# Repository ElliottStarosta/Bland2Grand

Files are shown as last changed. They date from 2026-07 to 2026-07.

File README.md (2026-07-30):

<div align="center">
  
# Bland2Grand

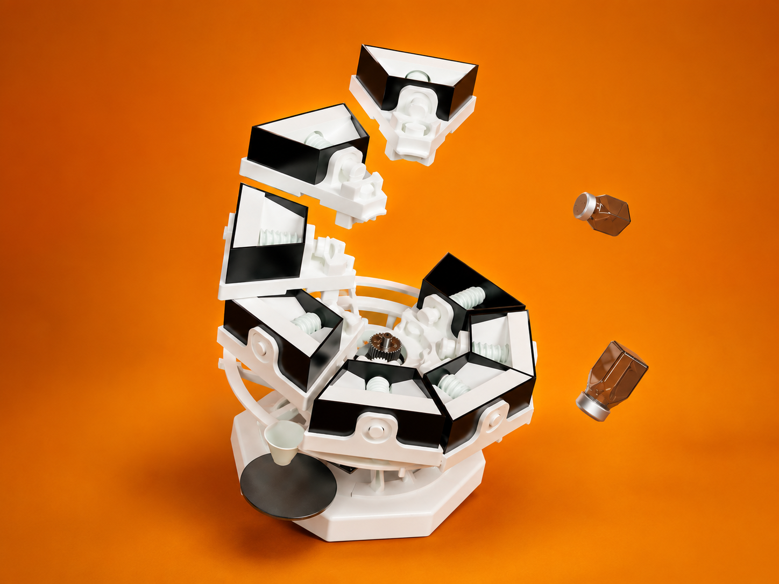
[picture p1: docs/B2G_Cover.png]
Bland2Grand automatic spice dispenser


### Automatic AI‑Powered Spice Dispensing System

**Arduino UNO Q • Flask • React • Load Cell Feedback • Custom Recipe Generation**

Search for a recipe (or build your own blend), choose the number of servings, and Bland2Grand automatically dispenses each spice with real-time weight feedback.

</div>

---

## Features

- 8-slot automatic spice carousel
- Weight-based dispensing with HX711 load cell
- React touchscreen interface
- Flask orchestration backend
- Arduino firmware controlling motors and sensors
- AI-assisted custom spice blend generation
- Live dispense updates using Server-Sent Events

---

## System Architecture

```text
Phone / Browser
      │
      ▼
React UI (5173)
      │
 REST + SSE
      │
      ▼
Flask Backend (5000)
      │
 HTTP + UDP
      │
      ▼
Arduino UNO Q
      │
 GPIO
      │
      ▼
Carousel • Auger • Load Cell
```

The frontend never communicates directly with the Arduino. Flask coordinates every dispense operation, receives progress updates from the Arduino, and streams them to connected clients using Server-Sent Events.

---

## Engineering Journals

Development was documented weekly throughout the project.

| Week | Journal |
|---|---|
|1|https://lying-denim-736.notion.site/Journal-1-33765230a78b8010af24f441907a132c?pvs=73|
|2|https://lying-denim-736.notion.site/Journal-2-33765230a78b808d91aac0a6b3ddb459?pvs=73|
|3|https://lying-denim-736.notion.site/Journal-3-33765230a78b80e9b983e4aa1db35312?pvs=4|
|4|https://lying-denim-736.notion.site/Journal-4-33765230a78b8081bd38f594ebceb503?pvs=73|
|5|https://lying-denim-736.notion.site/Journal-5-33765230a78b80ebb033f5e4358f1c1f|
|6|https://lying-denim-736.notion.site/Journal-6-33765230a78b804fb087c1ad0b55b3ff?source=copy_link|
|7|https://lying-denim-736.notion.site/Journal-7-33765230a78b80bd848ce638972f48d1?pvs=74|
|8|https://lying-denim-736.notion.site/Journal-8-33765230a78b806ebfbeec2ee93a6579?pvs=74|
|9|https://lying-denim-736.notion.site/Journal-9-33765230a78b80528cf1d645e4d33567?pvs=74|
|10|https://lying-denim-736.notion.site/Journal-10-34865230a78b807989e8eb5f8e950e21?pvs=74|
|11|https://lying-denim-736.notion.site/Journal-11-3aa65230a78b80d28e6ce9d19c58a4de|

---

## Design Documentation

| Document | Description | File |
|---|---|---|
| **HRS**  | Hardware Requirements Specification | [docs/HRS.pdf](docs/HRS.pdf) |
| **PDD**  | Preliminary Design Document | [docs/PDD.pdf](docs/PDD.pdf) |
| **HDD**  | Hardware Design Document | [docs/HDD.pdf](docs/HDD.pdf) |
| **MGD**  | Maker's Guide Document | [docs/MGD.pdf](docs/Incomplete_MG.pdf) |

---

## Quick Start

1. Enable the **bland2grand** Windows hotspot.
2. Power the Arduino UNO Q.
3. Run the **Bland2Grand: Full Stack** VS Code task.
4. Forward port **5173** and set visibility to **Public**.
5. Open the forwarded URL on your phone or `http://localhost:5173` on your PC.

---

## Repository Structure

```text
Bland2Grand/
├── Bland2Grand_Arduino/
├── bland2grand-backend/
├── bland2grand-frontend/
├── docs/
├── generate_slots.py
└── .vscode/
```

---

## Updating Spice Slots

Edit `spice_slots.json`, keep slot numbers sequential, then regenerate shared configuration:

```bash
python generate_slots.py
```

---

## First-Time Development Setup

### Backend

```bash
cd bland2grand-backend
python -m venv venv
venv\Scripts\activate
pip install -r requirements.txt
python seed_recipes.py
```

Create `.env`:

```env
ARDUINO_URL=http://192.168.x.x
OPENROUTER_API_KEY=...
AI_MODEL=anthropic/claude-3-haiku
DATABASE_PATH=bland2grand.db
FLASK_PORT=5000
MOCK_ARDUINO=true
```

### Frontend

```bash
cd bland2grand-frontend
npm install
```

### Arduino

Open `Bland2Grand_Arduino` using PlatformIO and upload the firmware.

---

## Hardware

| Component | Purpose |
|---|---|
|Arduino UNO Q|Main controller|
|NEMA 23 + TB6600|Carousel motor|
|NEMA 17 + TB6600|Auger motor|
|HX711 + Load Cell|Weight feedback|

### Pinout

| Signal | Pin |
|---|-----|
|Carousel STEP|D5|
|Carousel DIR|D7|
|Auger STEP|D3|
|Auger DIR|D4|
|HX711 SCK|A0|
|HX711 DOUT|A1|

---

## Troubleshooting

| Problem | Solution |
|---|---|
|Arduino won't connect|Verify hotspot credentials in `main.cpp`.|
|UI loads but dispense fails|Check Flask and Arduino IP configuration.|
|Phone can't access app|Make sure port 5173 is Public.|
|Serial monitor unavailable|Close Arduino IDE or other serial applications.|

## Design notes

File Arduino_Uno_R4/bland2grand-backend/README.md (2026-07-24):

# Bland2Grand backend

Flask server between the React UI and the Arduino. Recipe search, dispense sequencing, SSE progress stream, optional AI blends via OpenRouter.

## Data flow

```
Frontend  ←SSE→  Flask  ←HTTP/UDP→  Arduino
                    ↕
                 SQLite
                    ↕
              OpenRouter (optional)
```

**Mock mode** (`MOCK_ARDUINO=true`, default): simulates dispensing in Python -- no hardware needed for UI work.

**Real mode** (`MOCK_ARDUINO=false`): POSTs each spice to the Arduino and waits for push callbacks before continuing.

## Files

| File | What it does |
|---|---|
| `app.py` | Route definitions (REST + SSE + Arduino push endpoints) |
| `config.py` | Reads `.env` |
| `database.py` | SQLite schema and recipe CRUD |
| `dispense.py` | Session thread, SSE broadcast, mock simulator, UDP weight listener |
| `search.py` | Category shortcut → name search → AI fallback |
| `ai_client.py` | OpenRouter JSON blend generation |
| `seed_recipes.py` | One-time ~100 recipe seed |
| `provision.py` | Push WiFi creds to Arduino over serial |
| `slot_config.py` | Shared slot names (generated from repo root) |

## Setup

```bash
cd bland2grand-backend
python -m venv venv
venv\Scripts\activate          # Windows
# source venv/bin/activate     # macOS/Linux
pip install -r requirements.txt
python seed_recipes.py         # safe to re-run (INSERT OR IGNORE)
python app.py
```

`.env` example:

```env
ARDUINO_URL=http://192.168.x.x
OPENROUTER_API_KEY=sk-or-...
AI_MODEL=anthropic/claude-3-haiku
DATABASE_PATH=bland2grand.db
FLASK_PORT=5000
MOCK_ARDUINO=true
```

## API (frontend-facing)

| Method | Path | Notes |
|---|---|---|
| GET | `/api/health` | `{ status, mock_arduino }` |
| GET | `/api/search?q=` | Up to 6 recipes; may hit AI if DB empty |
| GET | `/api/recipes/<id>` | Single recipe |
| POST | `/api/dispense` | `{ recipe_id, serving_count }` -- starts background thread |
| GET | `/api/status/stream` | SSE -- see event types below |
| POST | `/api/stop` | Cancel + UDP STOP to Arduino |
| POST | `/api/calibrate` | Update slot cal factor |
| POST | `/api/recipe` | Save custom blend |

## Arduino push routes

Called by firmware, not the browser:

| Method | Path | When |
|---|---|---|
| POST | `/api/arduino/indexing` | Carousel moving |
| POST | `/api/arduino/dispense-start` | Auger started |
| POST | `/api/arduino/weight-push` | Live weight (HTTP or UDP relay) |
| POST | `/api/arduino/spice-complete` | One spice done -- unblocks dispense loop |
| POST | `/api/arduino/session-complete` | All spices done |
| POST | `/api/arduino/fault` | Error |

Weight updates also arrive on **UDP port 5001** so the auger loop isn't blocked by HTTP.

## SSE events

`/api/status/stream` emits JSON lines:

| `type` | Useful fields |
|---|---|
| `connected` | Handshake |
| `heartbeat` | Keep-alive |
| `session_start` | `recipe_name`, `slots[]` |
| `indexing` | `slot`, `spice_name`, `slot_index` |
| `dispensing_start` | `target_weight` |
| `weight_update` | `current_weight`, `target_weight` |
| `spice_complete` | `actual`, `target`, `status` |
| `session_complete` | `recipe_name` |
| `session_error` | `message` |

## Search logic

1. Query matches a cuisine keyword (`mexican`, `cajun`, …) → return that category.
2. Else SQL `LIKE` on recipe name.
3. Else call OpenRouter, save as `"AI Generated"`, return the new row.

No API key → step 3 is skipped.

## Database

**recipes** -- `name`, `category`, `description`, plus `s1_cumin` … `s8_cayenne` (grams per serving).

**calibration** -- per-slot `cal_factor` (HX711 counts per gram).

## WiFi provisioning

After flashing firmware:

```bash
python provision.py
# or
python provision.py --port COM3 --ssid MyNet --password secret
```

Sends JSON over serial; Arduino replies `PROV:OK`.

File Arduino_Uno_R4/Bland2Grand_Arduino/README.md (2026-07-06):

# Bland2Grand Arduino firmware

PlatformIO project for the **Arduino UNO Q**. Drives carousel indexing, auger dispensing, load-cell feedback, and talks to Flask over WiFi.

## What runs where

`main.cpp` is the production sketch. It spins a small state machine:

```
IDLE → INDEXING → DISPENSING → PARKING → (next spice or done)
```

- **INDEXING** -- carousel steps to the target slot (shortest CCW path).
- **DISPENSING** -- auger runs; weight pushed over UDP so HTTP doesn't stall steps.
- **PARKING** -- half-rev forward to disengage the spur gear and avoid drips.

`USE_LOAD_CELL` in `main.cpp` picks closed-loop (HX711) vs dead-reckoning (cycle counts only).

## Hardware

| Part | Job |
|---|-----|
| UNO Q | Controller + LED matrix status |
| NEMA 23 + TB6600 | 8-slot carousel |
| NEMA 17 + TB6600 | Auger / half-spur gear |
| HX711 + load cell | Gram feedback (optional) |
### Pins (see `Constants.h`)

| Signal | Pin |
|---|-----|
| Carousel STEP / DIR | D5 / D7 |
| Auger STEP / DIR | D3 / D4 |
| HX711 DOUT / SCK | A1 / A0 |

## Source files

| File | Role |
|---|---|
| `main.cpp` | WiFi, HTTP :80, dispense FSM |
| `Constants.h` | Pins, speeds, gram/rev estimates |
| `CarouselDriver.h` | Slot indexing |
| `AugerDriver.h` | Bulk → settle → nudge dispense |
| `Scale.h` | HX711 wrapper |
| `WiFiComms.h` | WiFi, HTTP server, Flask pushes, UDP weight |
| `SlotConfig.h` | Generated spice names |

## Closed-loop dispense (load cell)

AugerDriver runs three phases when `USE_LOAD_CELL=1`:

1. **Bulk** -- fast run to ~85% of target by cycle count (scale is noisy while spinning).
2. **Settle** -- stop, wait for stable reads.
3. **Nudge** -- one auger cycle at a time until target or max taps.

Per-slot coast EMA learns how much spice keeps falling after the motor stops.

After each spice the auger reverses (back-purge) to re-seat the half-spur gear.

## WiFi

Static IP default: `192.168.137.50` on the `bland2grand` hotspot (gateway `192.168.137.1`).

Credentials at top of `main.cpp`. First boot with empty EEPROM can accept serial provisioning -- see backend `provision.py`.

Flask push target is `FLASK_SERVER_HOST` in `Constants.h`.

UDP: weight → port 5001 on the PC, STOP command listened on 8889.

## Build & flash

```bash
pio run
pio run --target upload
pio device monitor --baud 9600
```

VS Code task **Arduino: Flash** works too.

## PlatformIO libs

```
AccelStepper, HX711, AS5600, ArduinoJson, ArduinoOTA
```

(listed in `platformio.ini`)

## EEPROM map (approximate)

| Address | Content |
|---|---|
| 128–143 | Carousel position backup |
| 200–297 | WiFi SSID/password |

Exact layout may vary -- check `FlowModel.h` / `WiFiComms.h` if you're poking EEPROM directly.

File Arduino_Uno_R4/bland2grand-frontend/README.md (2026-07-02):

# Bland2Grand frontend

Touch-first kiosk UI for the spice dispenser. Dark theme, GSAP transitions, live bowl fill during dispense.

Stack: React 18, TypeScript, Vite, Tailwind, GSAP.

The app only talks to Flask (`/api/*`). Vite proxies those calls to `localhost:5000` in dev.

## Screen flow

```
IdleScreen (tap anywhere to wake)
    ↓
SearchScreen ──→ ResultsScreen ──→ ServingScreen ──→ DispensingScreen ──→ CompleteScreen
    │                                      ↑
    └── CustomRecipeScreen ────────────────┘
```

`App.tsx` owns routing, the 60s idle timer, and dispense lifecycle (`useDispenseStream`).

## Project layout

```
src/
├── App.tsx                 Screen router + idle overlay
├── main.tsx                React mount
├── index.css               Design tokens + global styles
├── types/index.ts          Recipe types, SSE event union
├── slotConfig.ts           Generated spice labels/colors (don't hand-edit)
├── hooks/
│   ├── useDispenseStream.ts   SSE session state
│   ├── useDebounce.ts
│   └── slotAudio.ts           Voice lines per slot
├── components/
│   ├── Header.tsx
│   ├── Bowl.tsx            SVG bowl + spice layers
│   ├── SlotRow.tsx         Per-spice progress bar
│   └── SpiceCard.tsx
└── screens/
    ├── IdleScreen.tsx      Screensaver + useIdleTimer export
    ├── SearchScreen.tsx
    ├── ResultsScreen.tsx
    ├── ServingScreen.tsx
    ├── DispensingScreen.tsx
    ├── CompleteScreen.tsx
    ├── CustomRecipeScreen.tsx
    └── lib/api.ts          Typed fetch helpers
```

## Run locally

Needs Flask on port 5000.

```bash
cd bland2grand-frontend
npm install
npm run dev        # http://localhost:5173
npm run build      # output in dist/
```

## Notable bits

**Bowl.tsx** -- Each spice gets a band in the SVG bowl. Grain texture is procedural (seeded random). Drip animation runs while a slot is actively dispensing.

**useDispenseStream.ts** -- `connectAndDispense()` opens SSE, waits for `connected`, then POSTs dispense so early events aren't dropped. Session state is a reducer over SSE payloads.

**IdleScreen.tsx** -- Full-screen overlay at z-40. `useIdleTimer(timeout, onIdle)` resets via `wakeUp()` when the user taps. GSAP timelines use an `initiated` ref so remounting doesn't replay entrance animations.

**CustomRecipeScreen.tsx** -- Build a blend in g, tsp, or tbsp. Unit picker bubbles animate out with GSAP; values convert through gram equivalents.

## Design tokens

Defined in `index.css` and mirrored in `tailwind.config.js`:

| Token | Value | Use |
|---|---|-----|
| `--color-bg` | `#080706` | Page background |
| `--color-card` | `#161411` | Cards |
| `--color-accent` | `#C8692A` | Primary orange |
| `--color-txt` | `#EDE9E0` | Body text |
| `--color-muted` | `#6A6662` | Secondary text |

Fonts: **Cormorant** (headings), **Outfit** (UI).

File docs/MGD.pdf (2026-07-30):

T E C H N I C A L M A N U A L

B L A N D 2 G R A N D

★

# Maker’s Guide

The Smart, Autonomous Carousel Spice Dispenser

VERSION 1.0 | | | REV. July 30, 2026 | | | DOC. B2G-MG-00 1

### Contents

1

BLAND2GRAND | Maker’s Guide | v1.0

# 1 Introduction

This Maker’s Guide is written for someone who has the printed/purchased parts to build one in front of them and wants to assemble it and get it running. It covers two supported controller boards:
Arduino UNO Q
The primary, currently supported build. The Flask backend, dispense logic, and MCU sketch all run on a single board, launched through Arduino App Lab.
Arduino UNO R4 WiFi
The original build. The backend and frontend run on a separate laptop, communicating with the Arduino over a mobile hotspot.
Follow Section 2 to physically assemble the machine, then Section 3 to install and launch the software for whichever board you have.

i At a Glance
Build Time
One week for printing and
assembly, and one
afternoon for software

Skill Level
Intermediate: soldering, 3D printing, basic CLI

Boards Supported
UNO Q (recommended),
UNO R4 WiFi

# 2 Assembly

### 2.1 Printing the Parts

i Printer and Material Notes
All printing for this build was done on a Bambu P1S and an A1 mini in Bambu Studio. Every part is printed in PETG. Unless a setting is called out below, use the slicer’s default profile. If your slicer doesn’t expose a listed setting, its own default is a safe substitute. A 3D printer with a minimum build volume of 257mm × 257mm × 257mm is required.

Every part in this guide starts from Bambu Studio’s stock 0.20mm Standard @BBL X1C profile. Only the settings listed under each category below are changed; everything else is left at default.
Category Legend
Parts are grouped into three categories by print requirements. This legend is used consistently for the rest of this section:
VEJ | Page 2 of 48

Category | Profile Summary
Category 1 Lightweight | 1 wall loop, 10% infill/wall overlap, support on (tree)
Category 2 Strong | 3 wall loops, 30% infill/wall overlap, support on (tree)
Category 3 Misc | Its own profile: Arachne walls, 3 wall loops, support on (normal)

Full Parts List
Part | Qty
Bevel Gear | 8
Auger Power Shaft | 8
Auger Power Gear (Full Spur) | 8
Auger Motor Mount (Shaft Adapter) | 1
Auger Motor Mount | 1
Auger | 8
Auger Bevel Attachment | 8
Auger End Cap | 8
Base BL, BR, FL, FR | 1 each
Base Plate BL, BR, FL, FR | 1 each
Carousel Drive | 1
Carousel Motor Mount | 1
Carousel Motor Mount (Spacer) | 1
Carousel Track (Upper Trunk) | 1
Carousel Track (Support Arm) | 7
Funnel Support Extension | 1
Internal Gear | 1
Motor Shaft Auger Power Gear (Auger Half Spur) | 1
Plate Holder | 1
Segment | 8
Segment (Lid) | 8
Segment (Insert) | 8
Segment (Fork) | 8
Segment (Container) | 8
Support Plate | 1
Support Ring (Back Ring Track) | 2

Part | Qty
Support Ring (LS Ring Track) | 1
Support Ring (RS Ring Track) | 1
Cycloidal Gearbox (Cover) | 1
Cycloidal Gearbox (Disc) | 1
Cycloidal Gearbox (Hover) | 1
Cycloidal Gearbox (Input) | 1
Cycloidal Gearbox (Output) | 1

Category 1: Lightweight
Part | Qty
Base BL, BR, FL, FR | 1 each
Base Plate BL, BR, FL, FR | 1 each
Carousel Track (Upper Trunk) | 1
Carousel Track (Support Arm) | 7
Funnel Support Extension | 1
Plate Holder | 1
Segment | 8
Segment (Lid) | 8
Segment (Insert) | 8
Segment (Fork) | 8
Segment (Container) | 8
Setting | Value
Wall Loops | 1
Infill / Wall Overlap | 10%
Support | On (Tree)

Strength tab | Support tab
Figure 1: Slicer settings for Category 1 (Lightweight) parts.

Category 2: Strong
Part | Qty
Carousel Drive | 1
Carousel Motor Mount | 1
Carousel Motor Mount (Spacer) | 1
Internal Gear | 1
Motor Shaft Auger Power Gear (Auger Half Spur) | 1
Support Plate | 1
Cycloidal Gearbox (Cover) | 1
Cycloidal Gearbox (Disc) | 1
Cycloidal Gearbox (Hover) | 1
Cycloidal Gearbox (Input) | 1
Cycloidal Gearbox (Output) | 1
Setting | Value
Wall Loops | 3
Infill / Wall Overlap | 30%
Support | On (Tree)

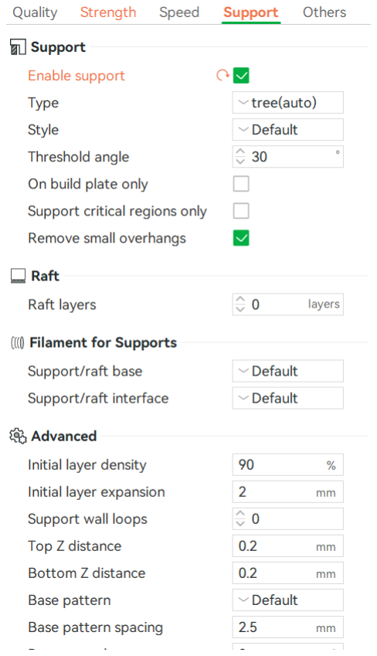
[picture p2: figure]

Strength tab | Support tab
Figure 2: Slicer settings for Category 2 (Strong) parts.

Category 3: Misc
Part | Qty
Auger | 8
Setting | Value
Wall Generator | Arachne
Layer Height | 0.2mm (initial 0.16mm)
Wall Loops | 3
Support | On (Normal)
Quality tab (1) | Quality tab (2)

Strength tab

Support tab

Figure 3: Slicer settings for Category 3 (Misc) parts, the Auger.

### 2.2 Mechanical Assembly

This section walks through the full mechanical build of Bland2Grand in eight parts: the auger motor, the carousel motor and cycloidal gearbox, the base, the load cell, the carousel segments, the tree trunk, and final assembly. Build the sub-assemblies in order, as each part is set aside and used in a later step.

i Before You Start
Have all printed parts from Section 2.1 sorted and within reach, along with super glue (or threadlocker), a hex key set, and the hardware called out in each step.

Part 1: Auger Motor Assembly

### 1 With the Auger Motor Mount (Shaft Adapter) and the half spur gear, super glue

the gear onto the shaft as shown below.

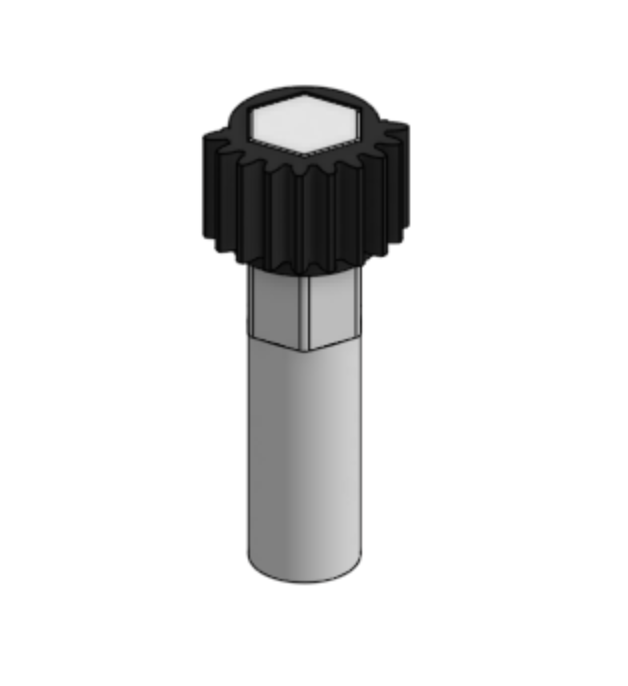
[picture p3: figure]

Figure 4: Half spur gear glued onto the auger motor shaft adapter.

### 2 Place the auger motor into the mount through the slit. Insert the four #6-32 ³

8

”
bolts into the motor (the motor is tapped, so no nuts are needed on this side).

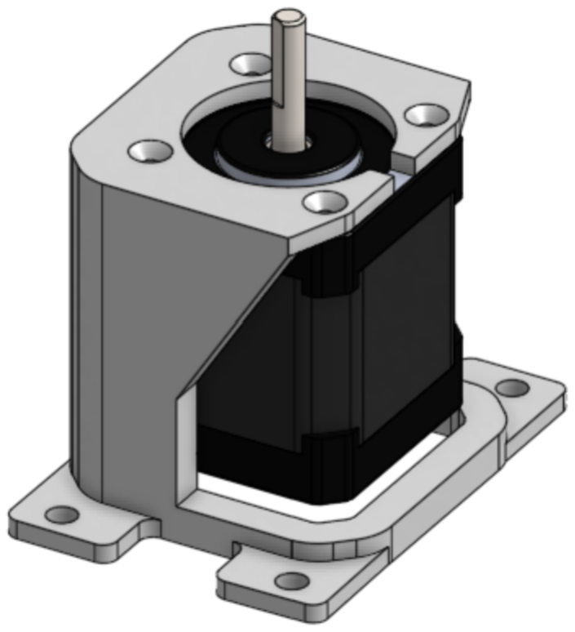
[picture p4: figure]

Figure 5: Auger motor seated into the Auger Motor Mount, viewed from the shaft side.

### 3 A second view of the same joint, showing the four #6-32 3

8

” bolts driven into the
motor’s tapped mounting holes.

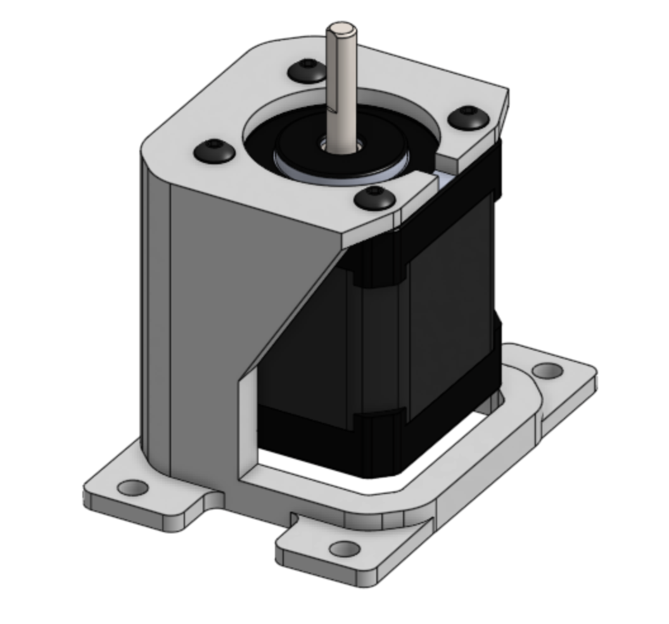
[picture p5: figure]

Figure 6: Auger motor mount, alternate angle showing #6-32 3
8

” bolt placement.

4 Slide the glued gear and shaft adapter (from Step 1) onto the motor shaft.

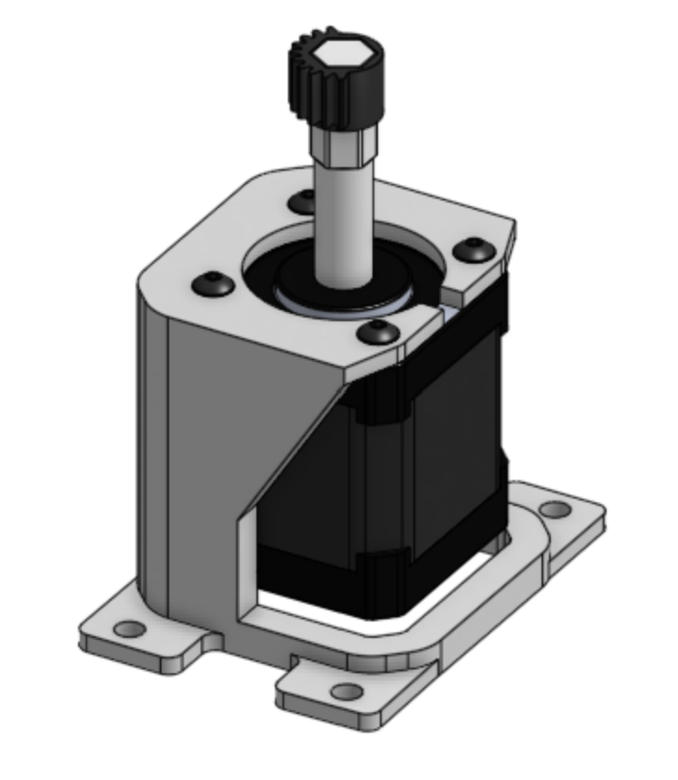
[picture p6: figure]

Figure 7: Gear and shaft adapter slid onto the auger motor shaft. Set the completed Auger Motor assembly aside.

Part 2: Carousel Motor and Gearbox Assembly

### 5 Place the carousel motor into the Carousel Motor Mount, ensuring the holes

on the mount line up with the holes on the motor.

Figure 8: Carousel motor aligned with the Carousel Motor Mount.

### 6 Place the gearbox spacer and housing onto the motor, ensuring that all mounting

holes are properly aligned.

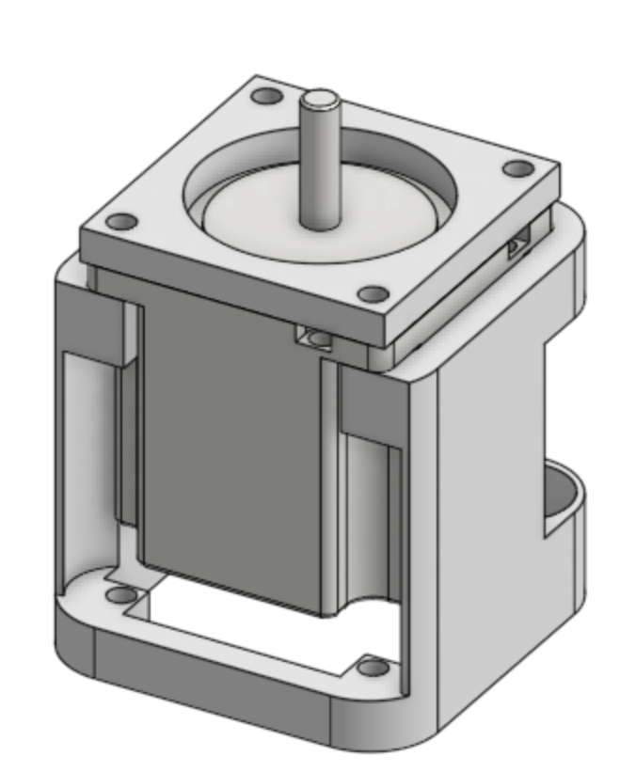
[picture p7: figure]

Figure 9: Gearbox spacer and housing installed onto the motor.

### 7 With the motor secured, the cycloidal gearbox housing sits on top, ready for the

disc and input adapter.

Figure 10: Cycloidal gearbox housing positioned above the mounted carousel motor.

### 8 Place the Cycloidal Gearbox (Disc) into the housing, then insert the input

adapter onto the motor shaft and into the disc.

Figure 11: Cycloidal disc lowered into the housing with the input adapter engaging the motor shaft.

9 A closer view showing the input adapter fully seated through the disc’s central bore.

Figure 12: Input adapter seated through the cycloidal disc.

10 Insert the output carriage into the holes in the cycloidal disc, as shown below.

Figure 13: Output carriage pins inserted into the cycloidal disc’s offset holes.

### 11 The Cycloidal Gearbox (Output) plate, which the carriage pins pass through to

transmit rotation.

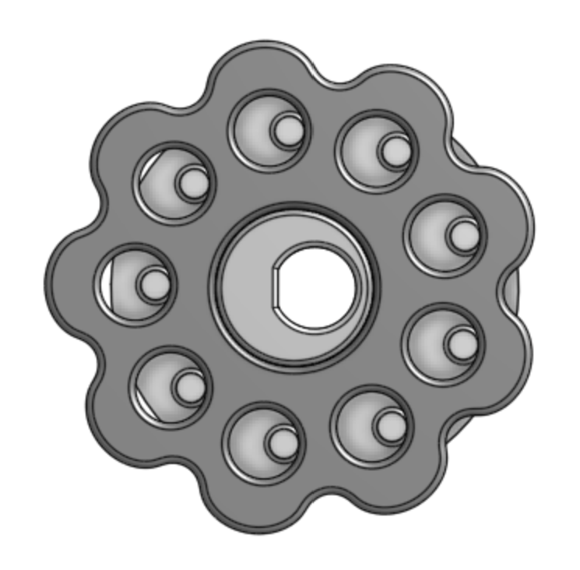
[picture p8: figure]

Figure 14: Cycloidal Gearbox (Output) plate.

12 Place the carousel drive gear in the cover between the top and bottom plates, as shown below. Then lower both parts onto the gearbox assembly.

Figure 15: Carousel drive gear seated in its cover between the top and bottom plates.

### 13 An exploded view of the same joint, showing the drive gear, cover, and gearbox

stack in assembly order.

Figure 16: Exploded view of the carousel drive gear over the assembled gearbox.

14 The stack fully lowered and seated together.

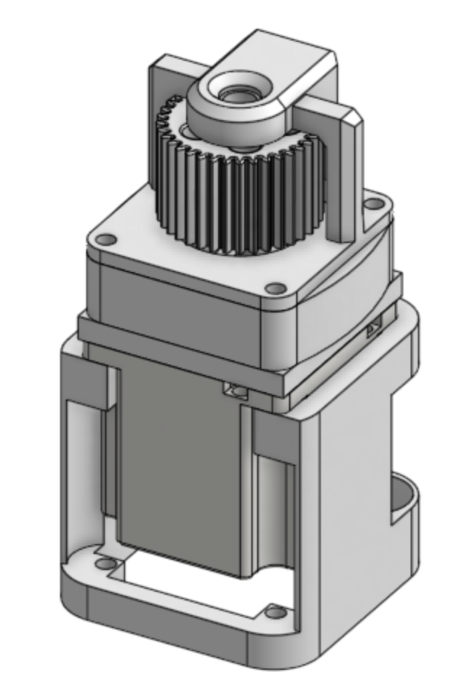
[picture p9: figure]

Figure 17: Carousel drive gear cover seated onto the completed gearbox assembly.

### 15 Insert four #10-32 1 ½” bolts into the holes and add matching nuts on the other

side. Tighten by hand.

Figure 18: Four #10-32 bolts and nuts securing the gearbox cover stack.

Set the completed Carousel Motor and Gearbox assembly aside.
Part 3: Base Assembly

### 16 Lay out the four Base (BL, BR, FL, FR) components and the dovetail key that joins

them.

Figure 19: The four base quadrants and dovetail key, prior to assembly.

### 17 Apply glue to the dovetail, then insert it into the center junction of the four

base components, ensuring it is properly aligned as shown below.

Figure 20: Dovetail key glued and inserted at the center junction of the four base quadrants.

### 18 Place the auger motor assembly (from Part 1) onto the base, aligning the

mounting holes with the designated holes as shown below. Insert four #10-32 1” bolts from underneath the base and secure them with four matching nuts. Tighten the bolts to firmly fasten the auger motor assembly in place.

Figure 21: Auger motor assembly secured to the base plate using four #10-32
1” bolts and matching nuts.

### 19 A closer view confirming the motor mount’s holes line up with the base before fas-

tening.

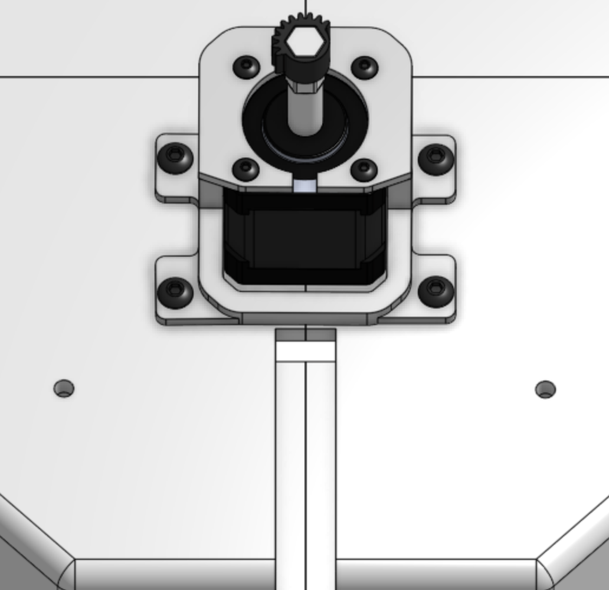
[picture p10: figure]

Figure 22: Close-up of the auger motor mount seated on the base.

20 Place the carousel motor and gearbox assembly (from Part 2) onto the base, as shown below. Insert four #10-32 1” bolts, this time with the bolt heads on the underside of the base and matching nuts on the topside.

Figure 23: Carousel motor and gearbox assembly aligned above the base’s center bore.

### 21 A view from underneath the base, showing the bolt heads seated against the base

with the center dovetail key visible through the bore.

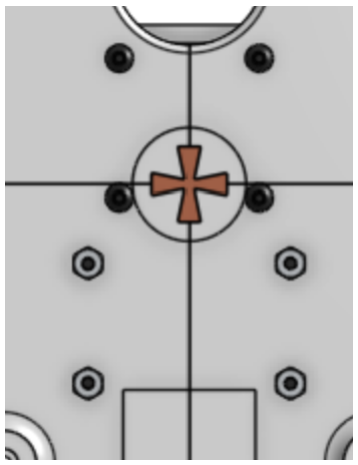
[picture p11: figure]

Figure 24: Underside view of the base showing bolt heads and the center dovetail key.

Set the Base assembly aside.

Part 5: Load Cell
22 With the load cell, super glue one of the load cell mounts to one of its ends, lining it up carefully.

Figure 25: Load cell mount glued to one end of the load cell.

### 23 Super glue the load cell mount and base to the flat part on the inside of the

base, as shown below.

Figure 26: Load cell and mount glued into position on the inside of the base.

24 A closer view of the load cell mount seated flush against the base’s inner wall.

Figure 27: Close-up of the load cell mount glued to the base’s inner face.

### 25 With the other load cell mount, super glue it to the opposite corner of the first

load cell mount, facing upwards.

Figure 28: Second load cell mount glued facing upward at the opposite corner.

26 Then, super glue the Plate Holder onto the load cell mount.

Figure 29: Plate Holder glued onto the upward-facing load cell mount. Part 6: Carousel Segment
Build one segment completely, then repeat the whole part seven more times for a total of eight.

### 27 Place a bearing into the bearing well of one of the carousel segments, making

sure it sits at the bottom of the well.

Figure 30: Bearing seated in a carousel segment’s bearing well.

28 Then place a Segment (Container) into the slot. Set aside.

Figure 31: Segment container placed into the segment shell.

29 With the Segment (Insert), place an auger into the tunnel as shown below. Then carefully lower the insert/auger into the container.

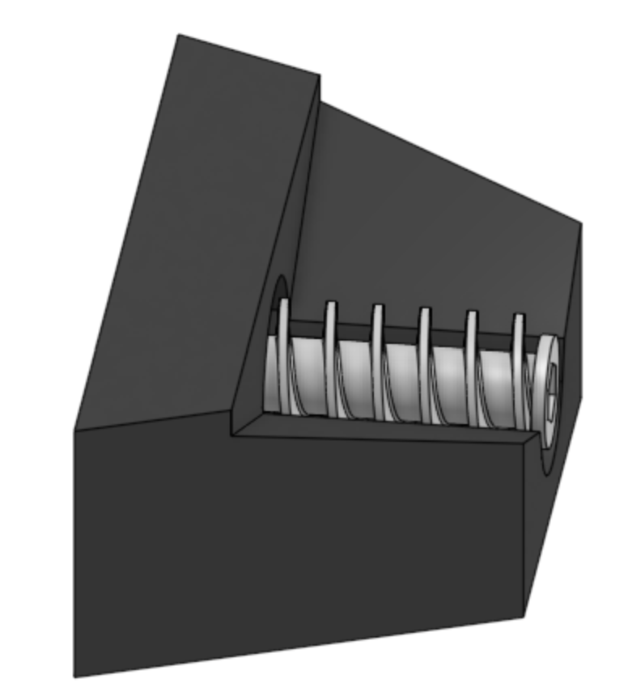
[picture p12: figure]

Figure 32: Auger placed into the tunnel of the segment insert.

30 The insert and auger lowered together into the container.

Figure 33: Segment insert and auger lowered into the segment container.

### 31 With the rear Auger End Cap, apply super glue to the hex side and insert it into

the fitting in the auger. Repeat this process on the front end cap.

Figure 34: Rear auger end cap glued and inserted into the auger’s hex fitting.

### 32 Front end cap and bearing detail, showing the hex bore that mates with the auger

shaft.

Figure 35: Front auger end cap and bearing hex-bore detail.

### 33 Turn the assembly over. With the Segment (Fork), apply super glue to the

spaces shown below and insert the fork.

Figure 36: Segment fork glue points on the underside of the segment.

34 The fork seated and glued into place on the flipped segment.

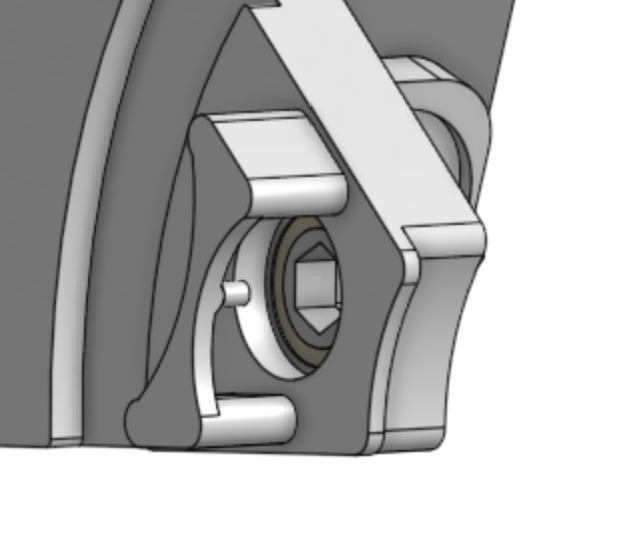
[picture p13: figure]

Figure 37: Segment fork inserted and glued in place.

35 Place one of the Auger Power Gears (Full Spur) onto the stud of the fork.

Figure 38: Full spur gear placed onto the fork’s stud.

### 36 Place a Bevel Gear onto the auger end cap, applying a bit of super glue to the

shaft beforehand.

Figure 39: Bevel gear glued onto the auger end cap’s shaft.

37 Place a matching bevel gear on the bearing, lining it up with the hex bore. Then insert the hex shaft through both gears.

Figure 40: Matching bevel gear aligned to the bearing’s hex bore.

38 The hex shaft fully seated, meshing both bevel gears.

Figure 41: Hex shaft seated through the meshed bevel gear pair.

i Repeat for All Eight
Repeat Steps 27–38 seven more times, for a total of eight completed segments, before continuing.

39 Line up all eight segments side by side, forming the full carousel ring.

Figure 42: All eight segments arranged side by side, viewed from above.

40 The segments joined together into a single ring assembly.

Figure 43: Eight segments joined into the assembled carousel ring.

### 41 With the ring gear, place it in the center of all the segments and super glue it

in place.

Figure 44: Ring gear glued into the center of the assembled carousel. Set the completed carousel assembly aside.

Part 7: Tree Trunk

### 42 Place the lower trunk (identifiable as the one with the opening in the ring) onto

the base plate, encompassing the gearbox assembly.

Figure 45: Lower trunk lowered onto the base plate around the gearbox assembly.

### 43 Insert a #10-32 3

4

” bolt through each mounting hole in the base, then secure it with a matching nut on the topside. Ensure that all bolts are properly seated and tightened.

Figure 46: Support arms secured to the base plate using #10-32 bolts and nuts.

### 44 The lower trunk fully seated on the base, with the carousel drive and motor visible

through the center opening.

Figure 47: Lower trunk seated on the base, carousel drive visible through the center.

### 45 Place the upper trunk onto the lower trunk, lining up the holes between the

two. With the support plate, place it as shown.

Figure 48: Upper trunk aligned onto the lower trunk with the support plate positioned.

46 The upper and lower trunk sections joined, ready for fastening.

Figure 49: Upper and lower trunk sections joined together.

### 47 Insert a #10-32 3

4

” bolt and matching nut through each of the mounting holes as shown. Ensure that the bolts are properly seated and tightened.

Figure 50: #10-32 3
4

” bolts and matching nuts installed through the trunk’s aligned mounting holes.

### 48 Following the image below as a guide, insert the support arms and funnel into

the correct slots, then secure each component using two #10-32 3
4

” bolts and
matching nuts.

Figure 51: Support arms and funnel secured in the trunk’s slots using #10-32 3/4” bolts and matching nuts.

49 Support arms and funnel fastened in place with bolts and nuts.

Figure 52: Support arms and funnel secured with bolts and nuts.

Part 8: Final Assembly

### 50 With the support ring, place it on the support arms so the opening sits above

the funnel. Add super glue at the seams to lock it in place.

Figure 53: Support ring placed on the support arms above the funnel.

### 51 With the assembled carousel (from Part 6), place it on the ring track of the

upper trunk, making sure the ring gear meshes with the carousel drive.

Figure 54: Assembled carousel lowered onto the upper trunk’s ring track.

### 52 Place all the electronics and wiring into the base (Section 2.3), then enclose

it with the base plates.

Figure 55: Electronics and wiring routed into the base before closing with the base plates.

i Mechanical Build Complete
With Part 8 finished, the mechanical assembly is done. Continue to Section 2.3 for the electrical wiring if it isn’t already in place, then to Section 3 to install and launch the software.

### 2.3 Electrical Wiring

All wiring is routed beneath the base plate, keeping the carousel deck and inside the tree trunk clear of cable clutter. The PERF board, stepper drivers, and HX711 are mounted to the underside of the base; only the motor leads pass up through the base into the tower.

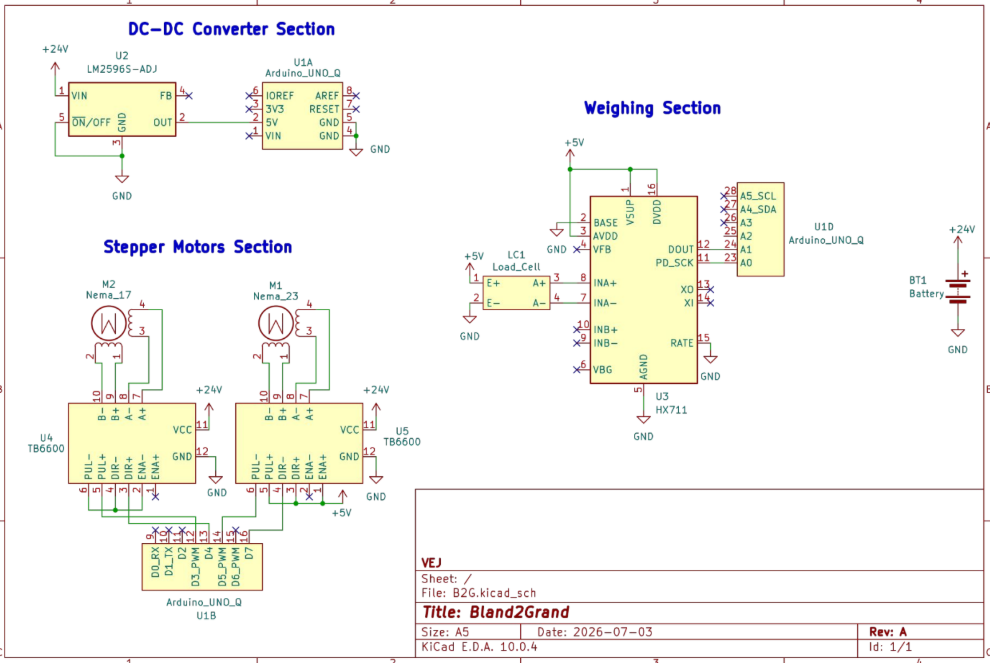
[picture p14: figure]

Figure 56: Full electrical schematic for Bland2Grand.

1 Plug the 4-pin wires into the NEMA 23 and NEMA 17 motors.

Figure 57: 4-pin wire connectors seated into the NEMA 23 and NEMA 17 motors.

2 Thread the wires through the routing hole shown below, down into the base.

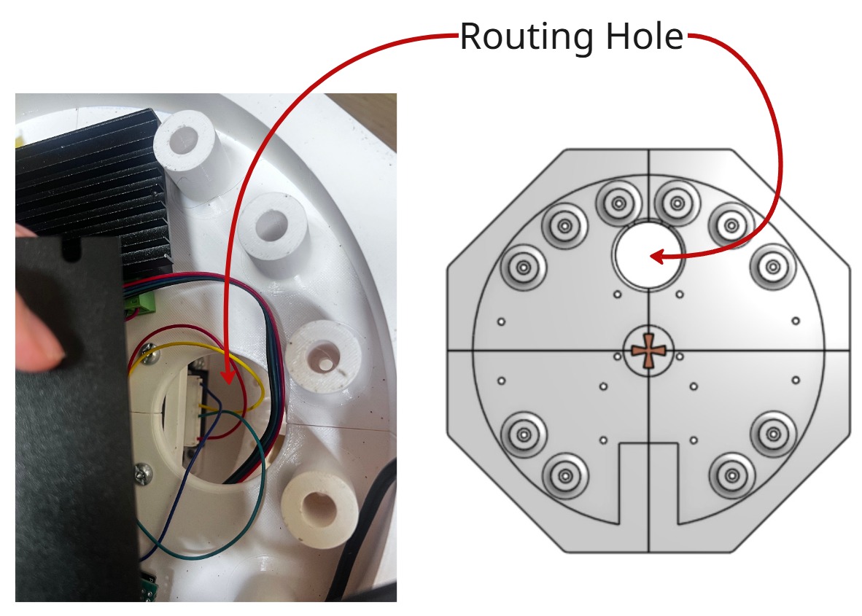
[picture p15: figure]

Figure 58: Motor wires threaded through the routing hole into the base.

### 3 Wire and solder the remaining connections according to the schematic

above.

Figure 59: Finished wiring, soldered and connected per the schematic.
What's Underneath the Base
- Controller board (UNO Q or UNO R4 WiFi): centered on the sub-plate, standoffmounted for airflow and easy access to the USB port.

- Stepper drivers: one per auger motor, mounted in a row along one edge, each wired to its corresponding controller pin group per the schematic.
- HX711 load cell amplifier: mounted close to the load cell itself to keep that signal run short, then a single 4-wire cable carries the amplified signal up to the controller.
- Power distribution terminal: splits the 24 V input to the motor drivers and steps it down as needed for the controller and load cell amplifier.

! Disconnect power before wiring changes
Always unplug the 24 V supply before connecting or disconnecting anything from the base. The stepper drivers in particular can be damaged if motor leads are connected or removed

# 3 Code and Software Setup

All source code for Bland2Grand is hosted on GitHub: github.com/ElliottStarosta/ Bland2Grand. (https://github.com/ElliottStarosta/Bland2Grand) The repository contains separate, self-contained builds for each supported board. Set up the one that matches your hardware.

### 3.1 Arduino UNO Q Setup (Recommended)

The UNO Q build runs the whole system (MCU sketch, Flask backend, REST API, SSE stream, and the built React frontend) as a single App Lab app on the board itself. There is no separate laptop backend/frontend to run.
Phase 1: Download the Project
1 Navigate to the Bland2Grand GitHub repository. (https://github.com/ElliottStarosta/Bland2Grand)

Figure 60: The Bland2Grand GitHub repository page.

2 Locate and click on the latest release.

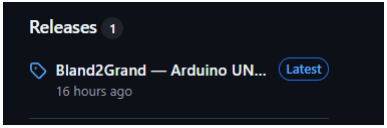
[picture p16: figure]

Figure 61: Latest release on the Releases page.

3 Scroll to the Assets section at the bottom of the release.

Figure 62: Assets section at the bottom of a release.

4 Download the zip file: Bland2Grand_Arduino_Uno_Q.zip.

Figure 63: Downloading Bland2Grand_Arduino_Uno_Q.zip from the Assets list.

Phase 2: Deploy to Arduino / App Lab
5 Open App Lab.

6 Select your board.

Figure 64: Selecting the connected UNO Q board in App Lab.

7 Click Create new app in the top right-hand corner.

Figure 65: The “Create new app” button in App Lab.

8 Click Import App and select the .zip file you downloaded in Phase 1.

Phase 3: Configure API Credentials
The AI-assisted custom blend feature calls out to OpenRouter. An API key is required for this feature to work (the rest of the app — search, dispensing, calibration — works without it).

9 Go to the OpenRouter keys page. (https://openrouter.ai/sign-in?redirect_url=https%3A%2F%2Fopenrouter.ai%2Fworkspaces%2Fdefault%2Fkeys)

10 Click New Key.

Figure 66: The “New Key” button on the OpenRouter keys page.

11 Fill out the required information.

Figure 67: OpenRouter new key creation form.

### 12 Copy the key shown on the confirmation screen right away — OpenRouter will

not show it to you again.

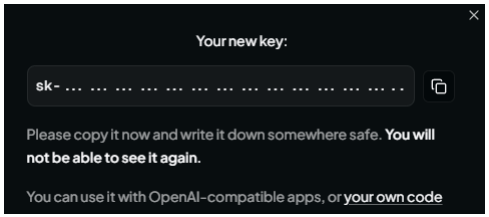
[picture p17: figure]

Figure 68: The one-time key reveal screen after creating a key.

### 13 Update the relevant environment variables for the app, most importantly

OPENROUTER_API_KEY.

Figure 69: Example environment configuration for the UNO Q app.

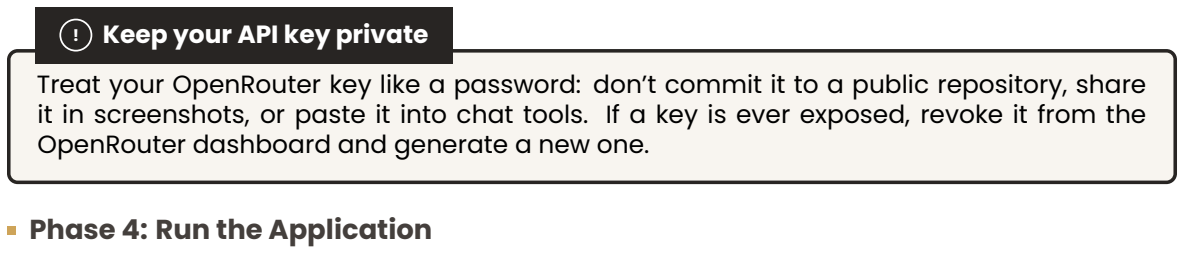
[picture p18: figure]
! Keep your API key private; Phase 4: Run the Application

Treat your OpenRouter key like a password: don’t commit it to a public repository, share it in screenshots, or paste it into chat tools. If a key is ever exposed, revoke it from the OpenRouter dashboard and generate a new one.

### 13 Set the application to run on startup by clicking the down arrow at the top

left-hand side of the screen, next to “Bland2Grand”.

Figure 70: The startup dropdown next to the app name in App Lab.

14 Toggle the Run at startup option to enabled.

Figure 71: Enabling the “Run at startup” toggle.

### 15 Click the Run button in the top right-hand corner of the screen. App Lab uploads

the MCU sketch and starts the Flask app on the board’s Linux side.

### 16 Access the web server by opening the board’s address on port 5000 (the port de-

clared in app.yaml) in your browser.

17 You are now ready to use Bland2Grand.

i Why enable Run at startup
With Run at startup enabled, the UNO Q automatically relaunches the Bland2Grand app any time it’s powered on or rebooted, so you don’t need App Lab open to bring the machine back up after a power cycle.

i No separate frontend server
Unlike the UNO R4 build below, the UNO Q serves the built React frontend directly from the same Flask app that handles the API, so there is nothing else to start or forward — one board, one port, one app.

### 3.2 Arduino UNO R4 WiFi Setup

The UNO R4 build splits the system across three pieces: firmware on the Arduino, a Flask backend, and a React frontend, both of the latter run on a laptop and communicate with the Arduino over WiFi. This section assumes the hardware is already assembled
and wired per Section 2, and that the Bland2Grand_Arduino, bland2grand-backend, and bland2grand-frontend folders (and the provided .vscode/tasks.json) are on the laptop
that will run the software.
Hardware Power-On

### 1 Place the machine on a flat, level surface — the load cell platform must stay level

to within 2◦

for accurate readings.

2 Connect the 24 V power supply to the wall.

3 Confirm each of the 8 spice containers is loaded and seated.

4 Place an empty bowl on the scale platform. The scale tares before each dispense, so the exact bowl weight does not matter.

### 5 Make sure the host laptop is powered on and ready to start its mobile hotspot (see

below). The Arduino and the phone running the web app both need to join it. Launching the Software
All software is launched from VS Code using the provided tasks.json. Open the project workspace in VS Code, then open the Command Palette with Ctrl+Shift+P and select Tasks: Run Task.

Figure 72: VS Code Command Palette showing “Tasks: Run Task” selected.
Two compound tasks are available:

Task Name | What it does
Bland2Grand: Full Stack | Flashes firmware to the Arduino, opens the serial monitor, starts the Flask backend, and starts the Vite frontend, which is all in parallel. Use this for a full bring-up from scratch.
Bland2Grand: Backend + Frontend | Starts only the Flask backend and the Vite frontend. Use this when the Arduino is already flashed and running. This is the task to run for a demo.

i What Full Stack does automatically
The Arduino: Flash + Serial subtask does three things before flashing: it starts the Windows mobile hotspot (so the Arduino has a network to connect to), kills any open serial monitor that would block the port, then runs pio run --target upload followed by pio device monitor --baud 9600. No manual hotspot setup or port management is needed.

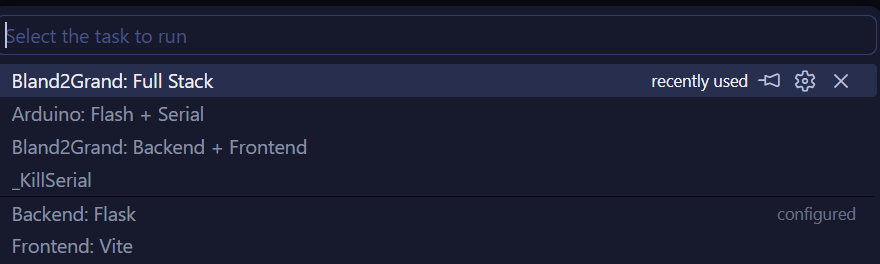
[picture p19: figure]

Figure 73: VS Code task picker showing the available Bland2Grand tasks.
Once the Backend + Frontend task is running, the web app is accessible from any device on the same network at:

http://{laptop_ip}:5173
The laptop’s IP address is printed in the Vite terminal panel when it starts. On the Arduino’s serial monitor you will also see the IP it received from the hotspot, which confirms the two devices are on the same subnet.
First-Time Backend Setup
If this is the first time running the backend on this laptop, set it up once before using the VS Code tasks:

1 cd bland2grand -backend
2 python -m venv venv
3 venv\Scripts\activate
4 pip install -r requirements.txt 5 python seed_recipes.py

Create a .env file in bland2grand-backend/:

1 ARDUINO_URL=http://192.168.x.x
2 OPENROUTER_API_KEY=YOUR_KEY_HERE
3 AI_MODEL=anthropic/claude -3-haiku 4 DATABASE_PATH=bland2grand.db
5 FLASK_PORT=5000
6 MOCK_ARDUINO=true

1 cd bland2grand -frontend
2 npm install
Open Bland2Grand_Arduino in PlatformIO once to confirm it builds before relying on the VS Code task to flash it.

MOCK_ARDUINO=true simulates dispensing in software with no hardware attached. This is useful for testing the app without the machine. Set it to false once the Arduino is flashed and wired, so the backend talks to the real hardware.

# 4 Using Bland2Grand

Once your board is flashed and the app is running (Section 3.1 or Section 3.2), everything from here on is identical regardless of which board you built. You interact with Bland2Grand entirely through a web app on your phone: the machine handles all indexing, dispensing, and weight confirmation autonomously and reports the result back in real time.

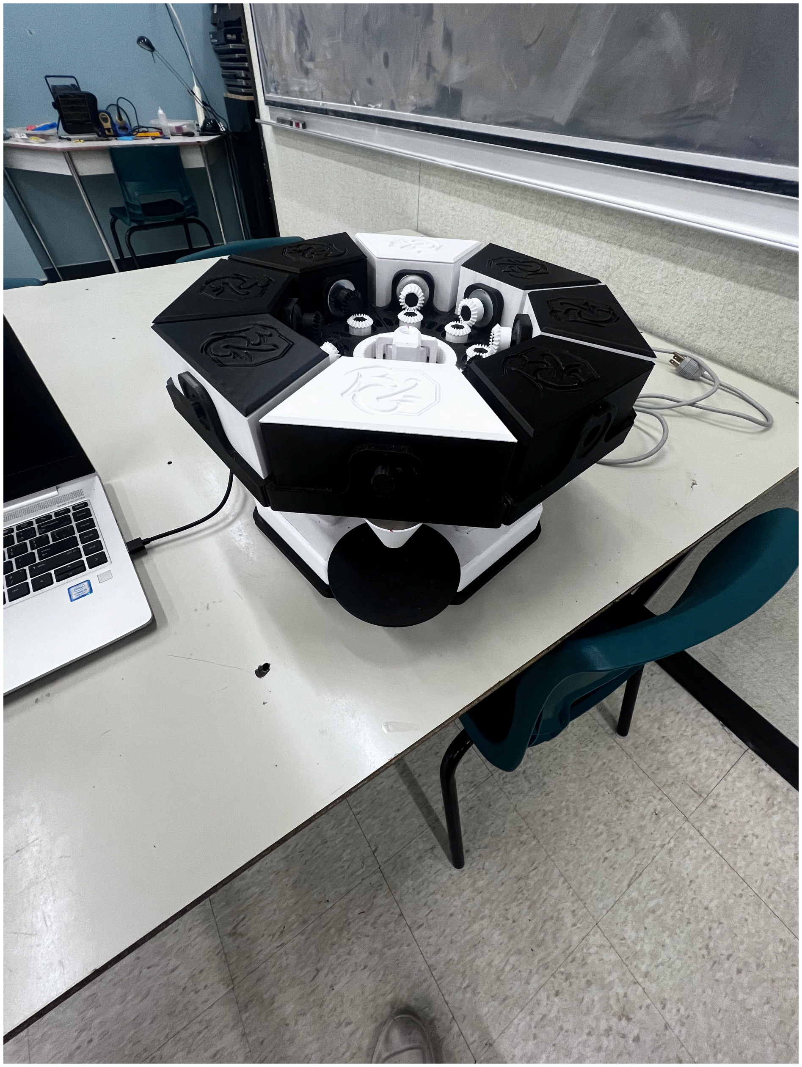
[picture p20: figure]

Figure 74: Bland2Grand assembled system, ready to dispense.

### 4.1 Powering On and Preparing to Dispense

### 1 Place the machine on a flat, level surface. The load cell platform must stay level

to within 2° for accurate readings — avoid uneven countertops or surfaces that vibrate.

### 2 Connect power to the board. 24 V for the UNO R4 build, or the UNO Q’s own power

input if that’s your build.

### 3 Verify spice containers are loaded. Each of the 8 slots should hold its designated

spice (see the slot map in Section 4.3). Friction-fit lids pull straight off — do not twist.

### 4 Place an empty bowl on the scale platform. Sit it flat and centred — the scale

tares before each dispense, so the exact bowl weight doesn’t matter.

Figure 75: Bowl placed on the scale platform at the base of the machine.

### 5 Confirm the app is reachable. Open the board’s URL on your phone (port 5000 for

UNO Q, or http://{laptop_ip}:5173 for UNO R4) and make sure the phone is on the same network as the board.

i Same app, either board
The interface below is served identically whether the Flask app is running on the UNO Q itself or on a laptop for the UNO R4 build. Once the URL loads, the rest of this section applies exactly as written.

### 4.2 Using the Mobile Web App

Idle Screen: Tap to Wake
When you first open the URL, the idle screen appears: ambient coloured orbs drift across a dark background with the Bland2Grand logo and a pulsing tap indicator. Tap anywhere to wake the app.

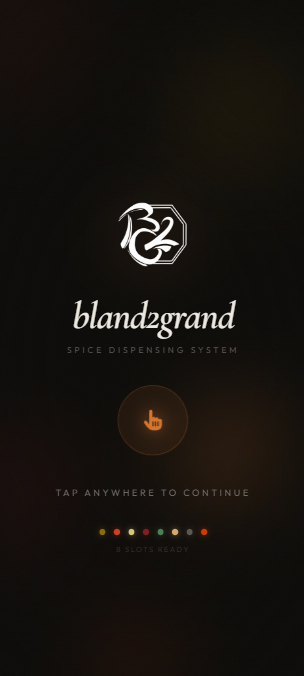
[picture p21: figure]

Figure 76: Idle screen. Tap anywhere to continue.

Search Screen: Find a Recipe
The search screen offers three ways to find a recipe:
1. Type a dish name into the search bar. Results appear automatically after a 2.5-second pause. If no local match exists, the AI generates a blend and saves it to the database for next time.
2. Tap a Featured Blend tile to jump directly to a popular recipe without searching.
3. Tap a cuisine category (Mexican, Indian, Italian, etc.) to browse everything in that category.

Figure 77: Search screen showing the search bar, featured blends, and cuisine category grid.
If the dish isn’t in the local database yet, an AI loading overlay appears while the blend is generated; this takes 1–3 seconds and only happens once per unique dish name. Every future search for the same dish is served instantly from the cache.

AI generating a blend

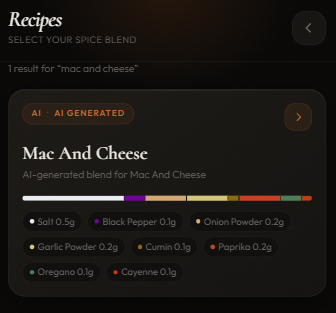
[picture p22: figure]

Generated result

Figure 78: AI loading overlay shown while generating a new recipe, and the resulting spice blend.

Results Screen: Choose Your Blend
Up to six matching recipes appear as cards, each showing the recipe name, a cuisine badge, a proportional spice colour bar, and the gram amount per serving for every active spice. Tap a card to select it.

Figure 79: Results screen showing matching recipe cards with spice colour bars and gram breakdowns.

Serving Screen: Set Portions
Use the large +/- buttons or the quick-pick row (1, 2, 4, 6, 8) to set how many servings to dispense. Gram amounts update live as you adjust. When ready, tap Dispense N servings.

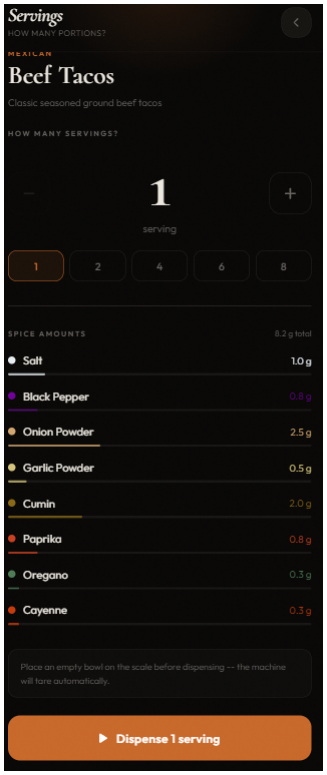
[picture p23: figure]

Figure 80: Serving screen with the counter set and gram breakdown updating live. Dispensing Screen: Watch It Work
While dispensing, the screen shows:

- A bowl visualisation that fills with layered spice in each slot’s colour as weight accumulates.
- A per-spice progress row with a live bar, status icon (rotating for indexing, spinning for dispensing, checkmark for done), and current vs. target weight.
- A circular progress ring showing overall completion percentage.
- A status line showing the current action (e.g. “Rotating…” or “Cumin”).
Each spice plays a voice announcement when the carousel reaches its slot.

Pulling the bowl off the scale during dispensing will throw off the weight readings for the rest of the session. Wait for the Complete screen before touching it.

Figure 81: Dispensing screen mid-session: bowl filling, per-spice rows, and progress ring.

Complete Screen: Your Blend Is Ready
Once every spice has been dispensed, the screen transitions to Ready, showing:
- A green checkmark (or amber warning if any slot timed out).
- A summary card listing the actual dispensed weight for each spice against its target.
- The total dispensed weight.
Retrieve your bowl and start cooking. Tap Start a new blend to return to the search screen.

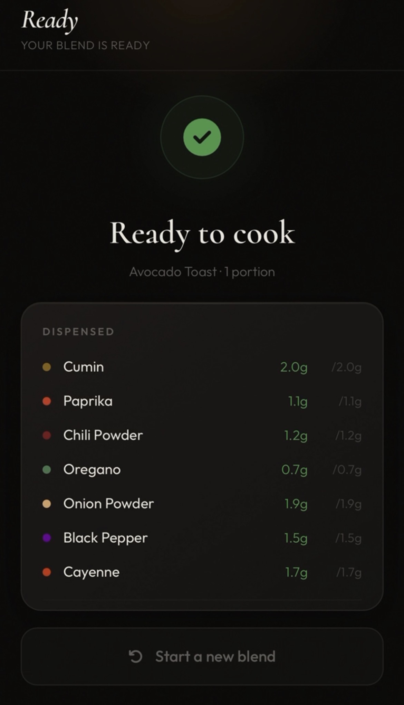
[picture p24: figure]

Figure 82: Complete screen showing the dispensed summary with accuracy indicators. Custom Recipe Builder
Tap Create Custom Blend on the search screen to build your own blend from scratch:
1. Enter a blend name and optional description at the top.
2. For each of the 8 slots, tap the unit label (tsp, tbsp, or g) to cycle between units. The amounts convert automatically using each spice’s density constant.

3. Use the +/- buttons to set the amount for each spice. A live proportional bar chart updates as you adjust.
4. Tap Save & Dispense to write the recipe to the database and proceed to the serving screen.

Figure 83: Custom recipe builder showing per-slot amount controls, unit picker bubbles, and live spice bar.

### 4.3 Refilling Containers

Each container has a friction-fit lid. Ensure the machine is not actively dispensing before opening the lid. Fill the container, then replace the lid, pressing it down until it is firmly seated.

Slot | Spice | Slot | Spice
1 | Salt | 5 | Cumin

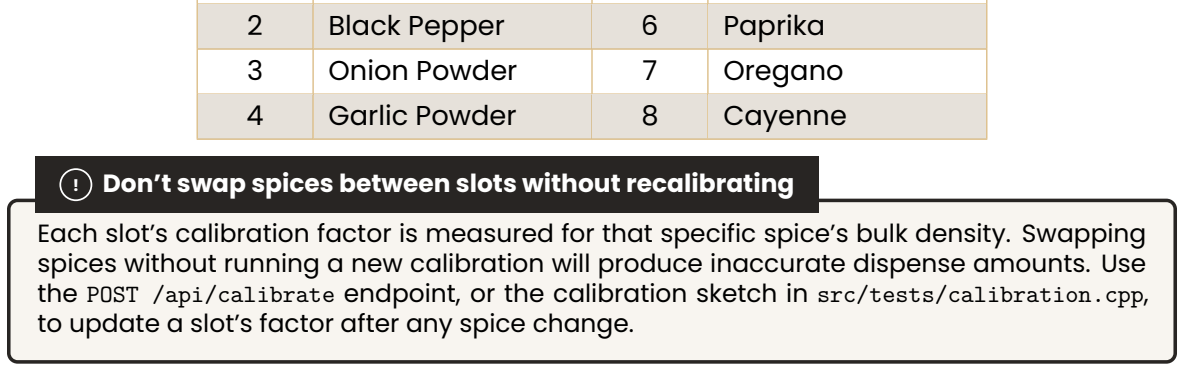
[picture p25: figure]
Black Pepper; Paprika; Onion Powder; Oregano; Garlic Powder; Cayenne

! Don’t swap spices between slots without recalibrating
Each slot’s calibration factor is measured for that specific spice’s bulk density. Swapping spices without running a new calibration will produce inaccurate dispense amounts. Use
the POST /api/calibrate endpoint, or the calibration sketch in src/tests/calibration.cpp,
to update a slot’s factor after any spice change.

### 4.4 Safety Notes

- A 60-second per-spice timeout halts the auger and aborts the blend if the target weight isn’t reached; protects against empty containers or a jammed auger.
- A 30-second watchdog halts all motors if the connection to the backend is lost mid-session.
- A scale overload fault triggers if more than 1 500 g is detected on the platform.
- Do not reach into the carousel area while the machine is powered on.

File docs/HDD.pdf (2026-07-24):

ONTARIO TEJ4M COMPUTER ENGINEERING TECHNOLOGY

HARDWARE DESIGN DOCUMENT

PROJECT


# Bland2Grand

### Smart Autonomous Carousel Spice Dispensing Appliance

Student Elliott Starosta

Course TEJ4M Computer Engineering Technology

Teacher Mr. Roller

Version 1.0

Date June 19, 2026

Hardware Design Document Bland2Grand | Version 1.0

### Contents

1 Introduction | 2
2 Updated System Description | 5
2.1.1 Carousel Drive: Cycloidal Gearbox Replaces Pinion-and-Ring . . . | 5
3 User’s Guide | 8
4 Beta Testing and Reporting Table (Appendix A) | 20
5 Reflection on Learning (Appendix B) | 29
6 Code (Appendix C) | 32
7 CAD (Appendix D) | 33
Elliott Starosta • TEJ4M | Page 1 of 33

### 1 Introduction

### 1.1 Project Overview

Bland2Grand is a smart, autonomous countertop spice dispensing appliance that eliminates the guesswork from seasoning food. The primary audience is home cooks who want precise, repeatable seasoning without measuring spoons — particularly those cooking for varying portion counts, experimenting with new cuisines, or lacking familiarity with the spices and flavor combinations commonly used in different culinary traditions. A user types the name of any dish into a mobile web application, the system retrieves matching spice blend options from a local recipe database, the user selects a blend and a serving count, and the machine autonomously dispenses the correct gram-accurate quantity of each required spice directly into a bowl placed below — with no manual measurement required at any step.

The physical machine is centred on a motorised carousel. Eight interchangeable spice containers are seated one per bay around the carousel ring. The carousel is driven by a NEMA 23 stepper motor (M1) through a 9:1 cycloidal gearbox for smooth, high-torque indexing. Once the correct container is indexed to the active position, a NEMA 17 stepper motor (M2) fixed to the tower frame below the carousel plane engages the container’s internal auger screw through a bevel gear interface, pushing spice through a downwardfacing nozzle into the bowl below. A NOYITO 1 kg load cell (LC1) paired with an HX711 24-bit ADC amplifier (U3) provides real-time gram-accurate weight feedback. An Arduino Uno R4 WiFi (U1) coordinates all motion, sensing, and wireless communication with a Flask web server running on a host laptop over the onboard 2.4 GHz 802.11 b/g/n WiFi module.

This Hardware Design Document (HDD) is the final capstone document for the Bland2Grand project. It documents what was actually built, how it differs from the Preliminary Design Document (PDD), how to use the system, and reflects on the overall learning process.

### 1.2 Related Documents

- Hardware Requirements Specification (HRS): The authoritative design contract defining all shall requirements for the system, authored March 8, 2026.
- Preliminary Design Document (PDD): The design document describing how the HRS requirements would be met, authored March 31, 2026.
- Development Journals (1–10): Weekly build logs documenting the full design and build process from March to June 2026.

### 1.3 Firmware, Platforms, and APIs

The firmware runs on the Arduino Uno R4 WiFi using the Arduino framework via PlatformIO. The following open-source libraries were imported:

Library | Purpose
AccelStepper v1.64 | Non-blocking step generation for M1 and M2
bogde/HX711 v0.7.5 | Load cell ADC reading; confirmed Uno R4 WiFi-compatible
robtillaart/AS5600 v0.6.7 | I2C encoder readout; imported but unused in final build
bblanchon/ArduinoJson v7.2.2 | JSON serialisation and deserialisation over WiFi
jandrassy/ArduinoOTA v1.1.1 | Over-the-air firmware update support

The Arduino firmware was written entirely in C++ and is structured as a flat state machine in main.cpp cycling through IDLE → INDEXING → DISPENSING → PARKING. Four subsystem headers encapsulate all hardware logic: CarouselDriver.h handles CCW slot indexing with a per-slot step correction constant; a back-purge reversal step provides passive anti-drip behaviour (see Section 2.1.3 for full rationale); per-spice timeout and watchdog behaviour are listed in Section 3.6; Scale.h wraps the HX711 with EMA filtering, a blocking stable-read routine, and overload detection; and WiFiComms.h manages WiFi connection, a minimal HTTP server on port 80, and outbound UDP weight-update packets on port 5001 (see Section 2.2 for the full network architecture and protocol rationale). FlowModel.h provides EEPROM-backed per-slot linear regression and coast estimation. A generate slots.py script at the repository root regenerates SlotConfig.h, slot config.py, and slotConfig.ts from a single spice slots.json source of truth, propagating any spice slot change to all three layers simultaneously.

The Flask backend is Python 3 with Flask, Flask-CORS, requests, and python-dotenv. app.py defines all REST and SSE routes; dispense.py runs the dispense session on a background thread, fans SSE events out to all connected clients via a per-client queue.Queue, listens for Arduino weight pushes on UDP port 5001, and implements a MOCK ARDUINO simulation mode that replays realistic dispensing behaviour in software so the frontend could be developed and tested without hardware. search.py implements a three-tier lookup: category keyword match, SQLite LIKE search, then OpenRouter AI fallback. database.py manages the SQLite schema and recipe CRUD, and seed recipes.py populates the database with approximately 100 curated recipes on first run.

The frontend is React 18 / TypeScript built with Vite, styled with Tailwind CSS, and animated with GSAP. App.tsx owns screen routing via a custom Screen union type, a 60-second idle timer, and the dispense session lifecycle. useDispenseStream.ts implements the SSE hook: connectAndDispense() opens the event source, waits for the connected acknowledgement before POSTing the dispense request (guaranteeing no events are dropped on slow connections), then folds every subsequent event into session state via a pure reducer. Bowl.tsx renders an SVG bowl that fills with procedurally-grained, seeded-random spice layers as weight accumulates, with a GSAP drip animation on the active slot. SlotRow.tsx shows a per-spice animated progress bar driven by GSAP.

IdleScreen.tsx implements the screensaver with floating ambient orbs and a pulsing tap indicator. CustomRecipeScreen.tsx provides per-slot amount controls with a unit-picker bubble that animates open and closed with GSAP, converting between grams, teaspoons, and tablespoons using per-spice density constants.

The AI recipe generation uses the OpenRouter API (anthropic/claude-3-haiku by default) to generate JSON spice blends for dishes not found in the local SQLite database. API calls are made at most once per unique dish name; all subsequent requests are served from the local database cache.

### 1.4 Acknowledgements and AI Assistance

CAD (OnShape): Michael and Jiayuan taught me how to use OnShape from scratch, walked me through the cycloidal gearbox epitrochoid geometry, helped with the structural base redesign (gussets and perimeter lip), and printed parts on their home printers throughout the mechanical phase.

Logo design: Naomi designed the Bland2Grand octagonal B/G lettermark logo.

Firmware debugging: Claude (Anthropic) was used to help debug specific firmware issues during development, including the EEPROM.commit() requirement on the Renesas RA platform and resolving AccelStepper speed transition behaviour.

Development methodology: All design decisions and implementation work are original to Elliott Starosta. Claude was used only as a reference tool during specific debugging sessions and was never used to generate complete code files.

### 1.5 Onboard Storage and Memory Architecture

The Arduino Uno R4 WiFi’s Renesas RA4M1 provides 256 KB of flash for program storage and 32 KB of SRAM for runtime variables, along with 8 KB of data flash used for EEPROM emulation to store non-volatile data across power cycles. FlowModel.h writes the learned grams-per-revolution constant for each of the 8 slots to EEPROM after every dispense, so the system’s calibration improves across power cycles rather than resetting to a default estimate every time the machine is unplugged. This is the only persistent storage in the system; recipe and session data live entirely on the host laptop’s SQLite database rather than onboard, since the Arduino’s limited flash and RAM are reserved for firmware logic and motor control rather than data storage. This division reflects a deliberate hardware tradeoff: the embedded controller is sized for real-time control, not data persistence, so all higher-volume storage (recipes, AI-generated blends, session history) is offloaded to the host machine’s conventional storage rather than burdening the microcontroller’s limited onboard memory.

One notable hardware quirk encountered during development was that the Renesas RA4M1’s EEPROM.commit() requirement differs from the byte-addressable EEPROM behaviour of older AVR-based Arduino boards (e.g. the Uno R3’s ATmega328P), where writes are immediate. On the RA4M1, EEPROM is emulated in flash, and writes must be explicitly committed in a single batch operation or they are silently discarded on reset. This is a direct example of how advances in microcontroller architecture (moving from native EEPROM to flash-emulated EEPROM for higher storage density) change low-level programming assumptions that carry over from older hardware generations.

### 2 Updated System Description

### 2.1 What Changed from the PDD

Several significant design decisions changed during the build phase. All changes are documented here as deviations from the PDD, with rationale.

### 2.1.1 Carousel Drive: Cycloidal Gearbox Replaces Pinion-and-Ring

PDD design: A pinion gear on M1’s shaft meshing externally with a ring gear on the carousel platform outer rim (GR = 2).

Actual design: A 9:1 cycloidal gearbox sits between M1’s shaft and the carousel center hub. The cycloidal disc (9 lobes) rolls inside a ring of 10 pins, with the output taken off through an output carrier.

Rationale: During physical assembly, it became clear that the external spur mesh was sensitive to center-distance variation under real rotating load. With eight loaded containers on the platform, any tilt of the carousel disc changes the mesh depth dynamically and causes skipped teeth and position errors. The cycloidal design distributes the contact load across multiple pins simultaneously (roughly half the pins are in contact at any time), is inherently self-centering, and has dramatically lower backlash. The 9:1 reduction also provides more torque to the carousel than the original 2:1 ratio. Michael identified this problem and recommended the change during the assembly phase.

### 2.1.2 AS5600 Encoder: Removed

PDD design: An AS5600 12-bit absolute magnetic encoder mounted coaxially on the M1 shaft, providing closed-loop angular position verification after every carousel index move.

Actual design: No encoder is fitted. The carousel operates entirely open-loop, relying on the AccelStepper step count to determine position.

Rationale: The AS5600 module purchased was listed by the supplier as compatible with the NEMA 23 motor shaft geometry. On arrival, the module’s magnet holder could not be made to maintain the required 0.5 mm axial air gap on the actual motor shaft diameter and shoulder geometry. Several mounting approaches were attempted but none produced stable angle readings. With insufficient time remaining in the build schedule to source a replacement encoder or design a new magnet holder, the encoder was removed from the design. As a consequence, HRS-3.1.21, HRS-3.1.22, and HRS-3.1.23 are not met in the final build. The carousel homing routine described in the PDD was also removed; on power-up the firmware assumes the carousel is at slot 1 and the user must manually verify this before the first dispense.

### 2.1.3 Auger Engagement: Bevel Gears Replace Half-Spur-Gear

PDD design: A half spur gear on M2’s shaft (teeth on 180° only) engaging a full spur gear on each container’s top face, with the toothless arc providing a positive mechanical cutoff.

Actual design: A bevel gear on M2’s shaft engages a matching bevel gear on each container’s auger shaft. The bevel gear pair transmits rotation through 90°. A back-purge routine in the firmware reverses the auger by the same number of steps taken during the dispense, sweeping residual powder back up the helix and creating a passive anti-drip condition.

Rationale: The half-spur gear concept was sound in CAD but the PDD’s spring-loaded jaw coupler variant created complex axial alignment requirements. The bevel gear approach that emerged during actual build is mechanically simpler: the motor gear and container gear are always in the same plane, engagement happens passively as the carousel rotates, and the back-purge provides the anti-drip function previously served by parking the toothless arc. The firmware now tracks total steps per dispense and issues an equal reverse move after each dispense completes.

### 2.1.4 Logic Level Shifting: Removed (Carried Forward from PDD)

As documented in the PDD Design Revision Note, HRS-3.3.1.1, HRS-3.3.1.2, and HRS-3.3.1.7 are superseded. The Funsto TB6600 units used for U4 and U5 specify a control signal input range of 3.3–24 V, which directly accommodates the RA4M1 output. No level shifter was installed.

### 2.1.5 Power Switch: Not Installed

PDD/HRS design (HRS-3.1.38): A panel-mounted SPST rocker switch on the 24 V line, providing a single hardware-level power cut to the entire system.

Actual design: No rocker switch was installed. To power the machine on and off, the 24 V supply is plugged into a power bar with its own on/off switch, which serves the same function.

Rationale: The switch cutout was not added to the enclosure before the final assembly was closed up, and there was insufficient time to reprint the affected panel. The power bar workaround is functionally equivalent for demonstration purposes (see HRS-3.1.38).

### 2.1.6 Power Supply Buck Converter Output

PDD design: LM2596S-ADJ trimmed to 5.0 V.

Actual design: Trimmed to 7.1 V, feeding the Arduino’s VIN pin rather than the 5 V pin, taking advantage of the RA4M1’s onboard voltage regulator. Testing results are documented in HRS-3.1.36.

### 2.1.7 Auger Tube Clearance

PDD design: 0.2 mm radial clearance between auger helix OD and tube ID.

Actual design: Increased to 0.3 mm per side (0.6 mm total diametric clearance) after empirical testing revealed the original clearance caused powder jamming with fine spices such as salt and cumin. The additional 0.1 mm per side was required to keep the auger-totube clearance ratio within the 5–15% range recommended for powder conveyors.

### 2.2 Network Architecture and Addressing

The system runs as a private local network created by the host laptop’s Windows mobile hotspot rather than relying on existing home WiFi infrastructure, so the demo is portable and does not depend on a venue’s network configuration. The laptop’s hotspot acts as a DHCP server, assigning IP addresses to two clients: the Arduino Uno R4 WiFi (firmware joins as a WiFi station and is assigned an address dynamically) and any phone running the web app. Because addresses are assigned dynamically rather than statically, the Arduino’s IP is read off the serial monitor at boot rather than hardcoded, and the Flask backend’s listening address is likewise read from the Vite terminal output rather than assumed; the User’s Guide instructs the user to confirm both devices report addresses on the same subnet before attempting to connect, which is the practical addressing check needed on a small DHCP-assigned network with no router-level configuration access.

Three distinct ports are used for three distinct communication purposes, a separation that exists specifically to prevent one type of traffic from blocking another: port 80 on the Arduino accepts inbound HTTP POST requests from Flask containing dispense commands; port 5000 on the laptop is where Flask’s REST API (/search, /dispense, /status, /calibrate, /recipe) is exposed to the phone’s browser; and port 5001 carries outbound UDP weight-update packets from the Arduino to Flask. UDP was chosen deliberately for the weight stream rather than HTTP, because UDP has no connection handshake and no retransmission guarantee, so a dropped or delayed packet on a momentarily congested hotspot cannot stall the Arduino’s stepper-control loop the way a blocking TCP handshake could. This represents a real network design tradeoff between reliability and the embedded controller’s real-time obligations: weight updates are frequent and individually low-stakes (the next one will arrive in well under a second if one is lost), so the lower-overhead, unreliable transport is the better fit, whereas dispense commands and final status reports are sent over the reliable, connection-oriented HTTP path, since a lost command would actually break the system.

### 2.3 Updated System Block Diagram

The block diagram below reflects the final as-built system architecture.


Figure 1: Updated as-built system block diagram.

### 3 User’s Guide

### 3.1 System Overview for the End User

Bland2Grand is a countertop appliance that automatically dispenses the right spice blend for any dish. You interact with it entirely through a web app on your phone. The machine handles all indexing, dispensing, and weight confirmation autonomously and reports the result back to your phone in real time.


Figure 2: Bland2Grand assembled system.

### 3.2 Hardware Setup

1. Place the machine on a flat, level surface. The load cell platform must remain level to within 2 degrees for accurate readings. Avoid placing on uneven countertops or surfaces that vibrate.
2. Connect the 24 V power supply. Plug the 24V power input into the wall.
3. Verify spice containers are loaded. Each of the 8 slots should contain its designated spice (see slot map in Section 3.5). Friction-fit lids pull straight off; do not twist.
4. Place an empty bowl on the scale platform. The bowl should sit flat and centred on the platform. The scale will tare before each spice dispense, so the exact bowl weight does not matter.


Figure 3: Bowl placed on the scale platform at the base of the machine.

5. Ensure the host laptop is on and connected to the hotspot. The Arduino connects to a mobile hotspot created by the laptop (see Section 3.3). The phone that will run the app must be on the same network.

### 3.3 Launching the Software

All software is launched from VSCode using the provided tasks.json. Open the project workspace in VSCode, then open the Command Palette with Ctrl+Shift+P and select Tasks: Run Task.

Figure 4: VSCode Command Palette showing “Tasks: Run Task” selected.

Two compound tasks are available:

Task Name | What it does
Bland2Grand: Full Stack | Flashes firmware to the Arduino, opens the serial monitor, starts the Flask backend, and starts the Vite frontend — all in parallel. Use this for a full bring-up from scratch.
Bland2Grand: Backend + Frontend | Starts only the Flask backend and the Vite frontend. Use this when the Arduino is already flashed and running. This is the task to run for a demo.

What Full Stack does automatically

The Arduino: Flash + Serial subtask does three things before flashing: it starts the Windows mobile hotspot (so the Arduino has a network to connect to), kills any open serial monitor that would block the port, then runs pio run --target upload followed by pio device monitor --baud 9600. No manual hotspot setup or port management is needed.


Figure 5: VSCode task picker showing the available Bland2Grand tasks.

Once the Backend + Frontend task is running, the web app is accessible from any device on the same network at:

http://{laptop ip}:5173

The laptop’s IP address is printed in the Vite terminal panel when it starts. On the Arduino’s serial monitor you will also see the IP it received from the hotspot, which confirms the two are on the same subnet.

### 3.4 Using the Mobile Web App

### 3.4.1 Idle Screen — Tap to Wake

When you first open the URL on your phone, the idle screen is shown: ambient coloured orbs drift across a dark background with the Bland2Grand logo and a pulsing tap indicator. Tap anywhere on the screen to wake the app.


Figure 6: Idle screen. Tap anywhere to continue.

### 3.4.2 Search Screen — Find a Recipe

The search screen has three ways to find a recipe:

1. Type a dish name into the search bar. Results appear automatically after a 2.5-second pause. If no local match exists, the AI generates a blend and saves it to the database for next time.
2. Tap a Featured Blend tile to jump directly to a popular recipe without searching.
3. Tap a cuisine category (Mexican, Indian, Italian, etc.) to browse all recipes in that category.


Figure 7: Search screen showing the search bar, featured blends, and cuisine category grid.

If the dish is not in the local database, an AI loading overlay appears while the blend is being generated. This takes 1–3 seconds and only happens once per unique dish name — all future searches for the same dish are served instantly from the cache.


AI Loading


Generated Result

Figure 8: AI loading overlay shown when generating a new recipe blend and the resulting generated spice blend.

### 3.4.3 Results Screen — Choose Your Blend

Up to six matching recipes are shown as cards. Each card displays the recipe name, cuisine category badge, a proportional spice colour bar, and the gram amount per serving for each active spice. Tap a card to select it.


Figure 9: Results screen showing matching recipe cards with spice colour bars and gram breakdowns.

### 3.4.4 Serving Screen — Set Portions

Use the large + and − buttons or the quick-pick row (1, 2, 4, 6, 8) to set how many servings to dispense. All gram amounts update in real time as you adjust. When ready, tap Dispense N servings.


Figure 10: Serving screen with the counter set to 1 servings and gram breakdown updating live.

### 3.4.5 Dispensing Screen — Watch It Work

The dispensing screen shows:

- A bowl visualisation that fills with layered spice in each slot’s colour as weight accumulates.
- A per-spice progress row with a live bar, status icon (rotating for indexing, spinning for dispensing, checkmark for done), and current vs. target weight.
- A circular progress ring in the top-right showing overall completion percentage.
- A status line showing the current action (e.g., “Rotating. . . ” or “Cumin”).

Each spice plays a voice announcement when the carousel arrives at its slot. Do not remove the bowl during dispensing.


Figure 11: Dispensing screen mid-session: bowl filling, per-spice rows, and progress ring.

### 3.4.6 Complete Screen — Your Blend Is Ready

When all spices have been dispensed, the screen transitions to the Ready screen. It shows:

- A green checkmark (or amber warning if any slot timed out).
- A summary card listing the actual dispensed weight for each spice alongside its target. Spices within 0.5 g of target are shown in green.
- The total dispensed weight.

Retrieve your bowl and start cooking. Tap Start a new blend to return to the search screen.


Figure 12: Complete screen showing the dispensed summary with accuracy indicators.

### 3.4.7 Custom Recipe Builder

Tap Create Custom Blend on the search screen to build your own blend from scratch.

1. Enter a blend name and optional description in the fields at the top.

2. For each of the 8 slots, tap the unit label (tsp, tbsp, or g) to cycle between units. Amounts convert automatically using the per-spice density constant.
3. Use the + and − buttons to set the amount for each spice. A live proportional bar chart at the top updates as you adjust.
4. Tap Save & Dispense to write the recipe to the database and proceed to the serving screen.


Figure 13: Custom recipe builder showing per-slot amount controls, unit picker bubbles, and live spice bar.

### 3.5 Refilling Containers

Each container has a twist-off lid. Ensure the machine is not actively dispensing, then twist counter-clockwise to open, fill, and replace clockwise until the lid seats firmly.

Slot | Spice | Slot | Spice
1 | Salt | 5 | Cumin
2 | Black Pepper | 6 | Paprika

Onion Powder; Oregano; Garlic Powder; Cayenne; 3.6 Safety Notes

Do not swap spices between slots without recalibrating

Each slot’s calibration factor is measured for its specific spice’s bulk density. Swapping spices without running a new calibration will produce inaccurate dispense amounts. Use the POST /api/calibrate endpoint or the calibration sketch in src/tests/calibration.cpp to update a slot’s factor after any spice change.

- A 60-second per-spice timeout halts the auger and aborts the blend if the target weight is not reached — this protects against empty containers or a jammed auger.
- A 30-second watchdog halts all motors if the Flask connection is lost mid-session.
- A scale overload fault triggers if more than 1 500 g is detected on the platform.
- Do not reach into the carousel area while the machine is powered on.

### 4 Beta Testing and Reporting Table (Appendix A)

Note on Appendix A

The table below lists every HRS requirement tested during the beta testing phase (May 22 – June 7, 2026), with hardware components involved, test method context, status, and tester notes. Columns are: HRS Requirement ID, Requirement (shall statement), Hardware Components Involved in Testing, Status, Date Tested, and Tester Notes / Observations. Of 63 requirements assessed: 46 Pass, 10 Pass with Modification, 3 Fail, and 4 Fail – Removed from Scope.

Req # | Requirement | Hardware Involved | Status | Date | Notes / Observations
HRS-3.1.1 | The system shall au-tonomously dispense a user-specified spice blend into a bowl placed on the integrated scale platform, requiring no manual mea-surement by the user. | NEMA-23 (carousel motor), NEMA-17 (engagement motor), both TB6600 drivers, HX711 load cell, Arduino Uno R4 WiFi | Pass | June 2, 2026 | Ran several full blends end-to-end with no man-ual intervention; every-thing landed in the bowl as expected.
HRS-3.1.2 | The system shall support a minimum of 8 indepen-dent spice channels, one per face of the octagonal carousel platform. | Carousel platform (3D-printed), NEMA-23, AS5600 encoder | Pass | June 2, 2026 | All 8 bays were loaded and cycled through in se-quence without issue.
HRS-3.1.3 | Each dispense operation shall achieve a target weight accuracy of ±0.3 g for any individual spice amount between 0.5 g and 50 g. | HX711 load cell, NOYITO 1 kg load cell, NEMA-17 en-gagement motor | Pass with modifi-cation | June 3, 2026 | Most readings were within tolerance, but a couple of trials with finer powders drifted slightly past ±0.3 g toward the end of the run.
HRS-3.1.4 | The system shall auto-matically scale all spice amounts proportionally when the user specifies a serving count between 1 and 20. | Flask backend (soft-ware), web interface (software) | Pass | June 1, 2026 | Spot-checked several serving counts across the valid range; amounts scaled proportionally as expected.
HRS-3.1.5 | The total time to complete a full 8-spice blend dis-pense for a single serving shall not exceed 120 sec-onds under normal operat-ing conditions. | NEMA-23, NEMA-17, both TB6600 drivers, HX711, Arduino Uno R4 WiFi | Pass | June 3, 2026 | Full 8-spice runs consis-tently finished comfort-ably under the limit dur-ing testing.
HRS-3.1.6 | The system shall operate from a single 24 V DC 6 A power supply. NEMA-23, NEMA-17, and both TB6600 drivers shall run from 24 V. All 5 V logic com-ponents shall be powered via an LM2596 buck con-verter. | 24 V 6 A AC/DC supply, LM2596 buck converter, both TB6600 drivers, Arduino Uno R4 WiFi, HX711 | Pass with modifi-cation | June 1, 2026 | Single supply confirmed for everything.
HRS-3.1.7 | The tower enclosure and all carousel components shall be entirely 3D-printed in PLA filament using school FDM printing equipment. | All 3D-printed struc-tural components | Pass with modifi-cation | May 30, 2026 | Most parts are PLA as planned, but a few mechanical parts were printed in PETG after PLA proved too brittle for those specific applica-tions.
HRS-3.1.8 | The tower enclosure shall have overall dimensions not exceeding 300 mm × 300 mm × 400 mm. | Completed tower enclosure (measure with ruler/calipers) | Pass | May 30, 2026 | Measured the assem-bled enclosure with cal-lipers; all three dimen-sions came in under the limit.

Req # | Requirement | Hardware Involved | Status | Date | Notes / Observations
HRS-3.1.9 | The carousel base shall be an octagonal rotating plat-form driven by the NEMA-23 stepper motor; each of the 8 faces shall accept one spice module. | Carousel platform, NEMA-23, 8 spice modules | Pass | May 28, 2026 | Carousel rotated through all 8 faces with each mod-ule seated correctly.
HRS-3.1.10 | Each spice module shall be mechanically interchange-able with any of the 8 carousel faces. | All 8 spice modules, carousel platform | Pass | May 28, 2026 | Swapped modules be-tween several faces; all seated and engaged cor-rectly regardless of posi-tion.
HRS-3.1.11 | Each module shall lock onto its carousel face via a quarter-turn bayonet or clip mechanism enabling tool-free removal and insertion. | Spice module bayo-net/clip mechanism, carousel face | Pass with modifi-cation | May 28, 2026 | The clip mechanism holds modules securely by hand, though it re-quires a bit more force than a true quarter-turn bayonet would.
HRS-3.1.12 | The auger screw shall be printed with a 0.2 mm ra-dial clearance between the auger helix OD and auger tube ID. | 3D-printed auger screw and tube (mea-sure with calipers) | Pass with modifi-cation | May 25, 2026 | See Section 2.1.7.
HRS-3.1.13 | The auger housing tube in-side each module shall be oriented at 20◦ above hori-zontal from input to nozzle. | 3D-printed auger module (measure angle with digital protractor) | Fail | May 25, 2026 | That was too difficult to CAD given my expertise, so each auger is parallel to the base (with no angle relative to the horizontal).
HRS-3.1.14 | Each module’s auger shaft shall protrude as a D-shaft or hex stub of minimum 8 mm engagement length to accept the NEMA-17 spring-loaded coupler. | Auger shaft stub, NEMA-17 spring-loaded coupler (measure engage-ment length) | Pass | May 26, 2026 | Engagement length checked with calipers across three different modules; consistent fit each time.
HRS-3.1.15 | The auger shaft shall in-clude a circular flange disc at the motor-end of the he-lix fitting the auger tube with 0.1 mm radial clear-ance. | 3D-printed auger shaft flange (mea-sure with calipers) | Pass | May 27, 2026 | Flange seated cleanly into the tube on every module tested; no bind-ing observed.
HRS-3.1.16 | The spice chamber shall in-clude a vertical window slot or transparent wall section no less than 40 mm tall for visual inspection. | 3D-printed module window/wall (visual inspection + mea-sure) | Fail | May 28, 2026 | I pivoted from using plas-tic containers to PETG containers, so the con-tainers are now not trans-parent.
HRS-3.1.17 | The fixed tower frame shall include a single output chute aligned with the en-gagement motor; chute walls angled ≥45◦ from ver-tical. | Tower frame chute (measure angle with protractor, verify alignment with all 8 modules) | Pass | May 29, 2026 | Chute angle verified with a protractor against the frame; spice slid through without lingering.

Req # | Requirement | Hardware Involved | Status | Date | Notes / Observations
HRS-3.1.18 | All 3D-printed parts in the direct spice flow path shall be printed at ≥50% infill density. | Auger tube, chute, nozzle sections (ver-ify slicer settings / cross-section) | Pass | May 30, 2026 | Cross-sectioned a spare printed part to confirm in-fill matched the slicer set-ting.
HRS-3.1.19 | The carousel shall be driven by a NEMA-23 (23HS5628) stepper mo-tor at 2.0 A via a TB6600 driver. | NEMA-23, TB6600 (carousel), 24 V sup-ply, multimeter for current verification | Pass | May 31, 2026 | Current draw measured at the driver terminals during a full carousel ro-tation; stayed within ex-pected range.
HRS-3.1.20 | The carousel TB6600 shall be connected to Uno R4 WiFi on STEP (pin 3) and DIR (pin 4); ENA tied high. | TB6600 (carousel), Arduino Uno R4 WiFi, signal wiring | Pass | June 1, 2026 | Toggled STEP/DIR manually via serial com-mands to confirm correct wiring before running automated sequences.
HRS-3.1.21 | The AS5600 shall be mounted coaxially on the carousel shaft within 0.5 mm axial gap; communi-cate via I2C at 400 kHz on SDA (A4) / SCL (A5). | AS5600 encoder, carousel shaft mag-net, Arduino Uno R4 WiFi, I2C bus | Fail – re-moved from scope | June 2, 2026 | See Section 2.1.2 for full rationale.
HRS-3.1.22 | The firmware shall use the AS5600 to verify carousel position after every index move; if deviation ±1.0◦ the firmware shall issue cor-rective steps. | AS5600 encoder, NEMA-23, Ar-duino Uno R4 WiFi firmware | Fail – re-moved from scope | June 3, 2026 | Encoder removed from design; see Sec-tion 2.1.2.
HRS-3.1.23 | On power-up the firmware shall perform a carousel homing routine using the AS5600 absolute angle to find Module 1. | AS5600 encoder, NEMA-23, Ar-duino Uno R4 WiFi firmware | Fail – re-moved from scope | June 4, 2026 | Homing routine removed along with encoder; see Section 2.1.2.
HRS-3.1.24 | The firmware shall en-force a minimum 1-second settling delay after the carousel motor stops be-fore enabling the NEMA-17 engagement motor. | NEMA-23, NEMA-17, HX711, Arduino Uno R4 WiFi firmware (verify with serial monitor timing) | Pass | June 5, 2026 | Timed the settle delay with the serial moni-tor across several index moves; consistent each time.
HRS-3.1.25 | The engagement motor shall be a NEMA-17 (17HS4401S) at 1.5 A via a TB6600 on the 24 V rail. | NEMA-17, TB6600 (engagement), 24 V supply, multimeter | Pass | May 25, 2026 | Current draw on the en-gagement driver checked at idle and under load; both within expected bounds.
HRS-3.1.26 | The NEMA-17 shall be mounted on a fixed vertical rail above the carousel with output shaft oriented verti-cally downward. | NEMA-17 mount, ver-tical rail, 3D-printed bracket (visual + di-mensional check) | Pass with modifi-cation | May 26, 2026 | It now sits below the carousel, with its output shaft oriented vertically upward.

Req # | Requirement | Hardware Involved | Status | Date | Notes / Observations
HRS-3.1.27 | The NEMA-17 output shaft shall connect to the auger stub via a spring-loaded jaw coupler with ≥3 mm ax-ial compliance. | NEMA-17, spring-loaded jaw coupler, auger shaft stub | Pass with modifi-cation | May 27, 2026 | Bevel gear engagement used instead; see Sec-tion 2.1.3.
HRS-3.1.28 | The engagement TB6600 shall be connected to Uno R4 WiFi on STEP (pin 5) and DIR (pin 7); ENA tied high. | TB6600 (engage-ment), Arduino Uno R4 WiFi, signal wiring | Pass | May 28, 2026 | Verified signal wiring with a multimeter continuity check before powering up the system.
HRS-3.1.29 | The firmware shall imple-ment a three-stage speed ramp-down: 50% speed at 80% weight target, 15% at 95%, full stop at 100% with coil current removed after 500 ms. | NEMA-17, HX711, Arduino Uno R4 WiFi firmware (verify with serial log of motor speed vs weight) | Pass | May 29, 2026 | Watched the motor au-dibly slow at each ramp stage while monitoring weight on the serial log.
HRS-3.1.30 | The system shall use a NOYITO 1 kg full-bridge strain gauge load cell with an HX711 24-bit ADC. | NOYITO 1 kg load cell, HX711 module | Pass | May 30, 2026 | Load cell and amplifier confirmed present and wired correctly by visual and continuity inspection.
HRS-3.1.31 | The HX711 shall communi-cate with the Uno R4 WiFi via bit-banged 2-wire on pin 9 (DT) and pin 10 (SCK). | HX711, Arduino Uno R4 WiFi, signal wiring | Pass | May 31, 2026 | Bit-banged communi-cation confirmed stable across multiple consec-utive readings with no dropouts.
HRS-3.1.32 | The firmware shall perform a tare operation before each individual spice dis-pense after carousel set-tling. | HX711, Arduino Uno R4 WiFi firmware (verify tare via serial output before each dispense) | Pass | June 1, 2026 | Confirmed via serial out-put that the tare reading reset to zero before every dispense in a multi-spice run.
HRS-3.1.33 | The firmware shall imple-ment a 500 ms settling de-lay after the engagement motor stops before tak-ing the final confirmatory weight reading. | NEMA-17, HX711, Arduino Uno R4 WiFi firmware | Pass | June 2, 2026 | Settling delay observed consistently in the se-rial log immediately be-fore the final weight was recorded.
HRS-3.1.34 | The entire system shall be powered by a single 24 V 6 A AC/DC supply with a 5.5×2.1 mm barrel jack. | 24 V 6 A AC/DC supply, barrel jack adapter | Pass | June 3, 2026 | Power supply and bar-rel jack confirmed against the datasheet; connector fit was snug.
HRS-3.1.35 | The 24 V rail shall connect to both TB6600 drivers; carousel TB6600 set to 2.0 A, engagement TB6600 set to 1.5 A. | Both TB6600 drivers, 24 V rail, multime-ter (verify current limit pot settings) | Pass | June 4, 2026 | Current limit pots checked with a multi-meter for both drivers; values matched the intended settings.
HRS-3.1.36 | An LM2596 buck converter shall step 24 V down to 5 V ±0.1 V to supply the Uno R4 WiFi and HX711. | LM2596 buck con-verter, multimeter | Pass with modifi-cation | June 5, 2026 | See Section 2.1.6. Output measured at 7.1 V ± 0.1 V; stable under load.

Req # | Requirement | Hardware Involved | Status | Date | Notes / Observations
HRS-3.1.37 | The Arduino Uno R4 WiFi shall be powered via the 5 V pin from the LM2596 out-put. | LM2596, Arduino Uno R4 WiFi, 5 V wiring | Pass | May 25, 2026 | Arduino powered via VIN at 7.1 V from LM2596; see Section 2.1.6.
HRS-3.1.38 | The system shall have a dedicated power switch on the rear of the tower base that interrupts the 24 V sup-ply. | Power switch, 24 V supply wiring, tower enclosure | Fail – re-moved from scope | May 26, 2026 | See Section 2.1.5 for full rationale. A power bar with a dedicated switch serves as a functional equivalent for demonstra-tion purposes.
HRS-3.1.39 | The embedded controller shall be an Arduino Uno R4 WiFi (Renesas RA4M1, 48 MHz, onboard 2.4 GHz WiFi). | Arduino Uno R4 WiFi board (verify in IDE board selection / firmware) | Pass | May 27, 2026 | Board identity confirmed in the IDE and via the on-board chip markings.
HRS-3.1.40 | The firmware shall be written in C++ using the Arduino framework with libraries: AccelStepper, AS5600, HX711 bogde, WiFiS3, ArduinoJson. | Arduino Uno R4 WiFi firmware, Arduino IDE / PlatformIO | Pass with modifi-cation | May 28, 2026 | I do not use the AS5600 library.
HRS-3.1.41 | The firmware shall imple-ment a non-blocking main loop; all operations han-dled without delay() block-ing. | Arduino Uno R4 WiFi firmware (verify with concurrent motor + scale readings via se-rial monitor) | Pass | May 29, 2026 | Ran the scale and mo-tors concurrently while watching serial output; no stalling or blocking ob-served.
HRS-3.1.42 | The firmware shall ex-pose a JSON command interface over WiFi: re-ceive {carousel, grams}, respond {status, actual}. | Arduino Uno R4 WiFi firmware, Flask back-end, WiFi network | Pass | May 30, 2026 | Sent test JSON payloads from a separate script and confirmed the ex-pected response struc-ture came back.
HRS-3.1.43 | The firmware shall imple-ment a carousel sequenc-ing algorithm that sorts required modules by in-dex angle to minimise total carousel travel. | Arduino Uno R4 WiFi firmware, carousel mechanism (verify via serial log of rotation sequence) | Pass | May 31, 2026 | Logged the rotation order for a multi-spice blend and compared it against the expected minimal-travel sequence.
HRS-3.1.44 | The firmware shall imple-ment an emergency stop halting all motors if no command is received from Flask within a 30-second timeout. | Arduino Uno R4 WiFi firmware, WiFi net-work (test by discon-necting laptop mid-dispense) | Pass | June 1, 2026 | Disconnected the laptop mid-dispense and con-firmed the motors halted after the timeout elapsed.
HRS-3.1.52 | The engagement motor (NEMA-17) shall operate open-loop; the HX711 load cell is the sole feedback mechanism for stopping the dispense. | NEMA-17, HX711, Arduino Uno R4 WiFi firmware | Pass | June 2, 2026 | Ran several dispenses with the scale as the only stop condition; no positional feedback was used.

Req # | Requirement | Hardware Involved | Status | Date | Notes / Observations
HRS-3.1.53 | The firmware shall im-plement a per-spice 60-second dispense timeout, stopping the motor and reporting {status: time-out, actual} if target not reached. | NEMA-17, HX711, Arduino Uno R4 WiFi firmware (test with empty module) | Pass | June 3, 2026 | Ran an empty-module test and confirmed the timeout fired with the ex-pected status message.
HRS-3.1.45 | The Flask backend shall maintain a local SQLite database containing ≥100 pre-populated dish recipes. | Flask backend, SQLite database (verify record count via query) | Pass | June 4, 2026 | Queried the database directly to confirm the recipe count met the re-quirement.
HRS-3.1.46 | When a user submits a dish name the Flask back-end shall first query the local SQLite database for a case-insensitive partial match, targeting ¡100 ms response. | Flask backend, SQLite database, web interface (mea-sure response time) | Pass | June 5, 2026 | Timed several searches from the web interface; responses felt close to in-stantaneous.
HRS-3.1.47 | If no local match is found, the Flask backend shall call an AI language model API, validate the returned blend, and save it to the local database. | Flask backend, AI API (OpenAI or Anthropic), SQLite database, internet connection | Pass | May 25, 2026 | Searched for a dish not in the database and con-firmed a generated blend was returned and then cached.
HRS-3.1.48 | The Flask backend shall expose HTTP endpoints: GET /search, POST /dis-pense, GET /status, POST /calibrate, POST /recipe. | Flask backend (test each endpoint with a browser or curl) | Pass | May 26, 2026 | Hit each endpoint indi-vidually with a browser or curl and confirmed ex-pected responses.
HRS-3.1.49 | The Flask backend shall be accessible from any device on the same WiFi network at http://{laptop ip}:5000 without app installation. | Flask backend, WiFi network, mobile browser | Pass | May 27, 2026 | Accessed the interface from a separate phone on the same network without installing any-thing.
HRS-3.1.50 | The web interface shall up-date the dispense progress screen in real time at 2 Hz showing current weight and active carousel module. | Flask backend, web interface, SSE/polling, Arduino Uno R4 WiFi | Pass | May 28, 2026 | Watched the progress screen update smoothly during a live dispense.
HRS-3.1.51 | The system shall support a custom recipe builder in the web interface allowing blend creation and save to local database. | Flask backend, web interface, SQLite database | Pass | May 29, 2026 | Created a custom blend through the interface and confirmed it was saved and selectable afterward.
HRS-3.2.1 | The web interface shall be a single-page application with JavaScript DOM nav-igation and no full page reloads. | Flask backend, web interface (mobile browser test) | Pass | May 30, 2026 | Navigated through every screen without triggering a full page reload.

Req # | Requirement | Hardware Involved | Status | Date | Notes / Observations
HRS-3.2.2 | The search screen shall present a text input and Search button with auto-complete suggestions at a 300 ms debounce interval. | Flask backend, web interface, SQLite database | Pass | May 31, 2026 | Typed a dish name and watched suggestions ap-pear after a brief pause, as expected.
HRS-3.2.3 | The results screen shall present a maximum of 3 blend option cards each with blend name, spice list, amounts, and Select but-ton. | Flask backend, web interface (mobile browser test) | Pass with modifi-cation | June 1, 2026 | I made it display all pos-sible search results, with the recipes ranked from best to worst match.
HRS-3.2.4 | The serving size screen shall present a slider from 1 to 20 servings with real-time gram amount updates calculated client-side. | Web interface (client-side JavaScript) | Pass | June 2, 2026 | Adjusted the serving count across its range and watched gram amounts update immedi-ately.
HRS-3.2.5 | The dispense progress screen shall display one progress bar per spice with current vs target weight and a carousel position indicator. | Flask backend, web interface, Arduino Uno R4 WiFi, SSE | Pass with modifi-cation | June 3, 2026 | Made a status bar in-stead because it looked nicer and more user-friendly.
HRS-3.2.6 | The USB Type-C port on the Uno R4 WiFi shall remain accessible from outside the enclosure for firmware re-programming and serial debug. | Arduino Uno R4 WiFi, tower enclo-sure (physical access check) | Fail | June 4, 2026 | I enclosed the Arduino at the bottom of the ma-chine because I did not have time to implement structured cable manage-ment (I simply left all the wiring at the bottom).
HRS-3.3.1.1 | The Uno R4 WiFi shall drive the carousel TB6600 via STEP (pin 3) / DIR (pin 4) at 3.3 V logic; a 3.3–5 V level shifter shall be in-cluded. | Arduino Uno R4 WiFi, TB6600 (carousel), TXS0104E/BSS138 level shifter, oscil-loscope or logic analyser | Pass with modifi-cation | June 5, 2026 | No level shifter installed; TB6600 control input range (3.3–24 V) directly accommodates the RA4M1 output. See Section 2.1.4.
HRS-3.3.1.2 | The Uno R4 WiFi shall drive the NEMA-17 TB6600 via STEP (pin 5) / DIR (pin 7); same level shifter mod-ule as carousel TB6600. | Arduino Uno R4 WiFi, TB6600 (engage-ment) | Pass with modifi-cation | May 25, 2026 | No level shifter installed; TB6600 control input range (3.3–24 V) directly accommodates the RA4M1 output. Wiring continuity to correct pins was verified before powering up. See Sec-tion 2.1.4.
HRS-3.3.1.3 | The AS5600 shall commu-nicate via I2C on A4 (SDA) / A5 (SCL) at 400 kHz with 4.7 kΩ pull-ups to 3.3 V. | AS5600, Arduino Uno R4 WiFi, 4.7 kΩ resistors, I2C bus | Fail – re-moved from scope | May 26, 2026 | Since the encoder was never successfully mounted, the I2C bus and pull-up wiring for it were never connected.

Req # | Requirement | Hardware Involved | Status | Date | Notes / Observations
HRS-3.3.1.4 | The HX711 shall communi-cate via bit-banged 2-wire on pins 9 (DT) / 10 (SCK); RATE pin tied to GND for 10 SPS. | HX711, Arduino Uno R4 WiFi, signal wiring | Pass | May 27, 2026 | Confirmed RATE pin wiring and observed sta-ble readings consistent with the expected sample rate.
HRS-3.3.1.5 | The load cell shall connect to the HX711 via 4-wire ca-ble ≤200 mm (R: E+, Blk: E−, Wh: A−, Gr: A+). | NOYITO load cell, HX711, 4-wire ca-ble (measure cable length) | Pass | May 22, 2026 | Measured the load cell cable with the supplied wire harness; well within the length limit and wired per the colour conven-tion.
HRS-3.3.1.6 | All signal wiring shall use 22 AWG solid-core; all 24 V power and motor leads shall use 18 AWG stranded wire. | All internal wiring (visual inspection + AWG verification) | Pass | May 29, 2026 | Spot-checked wire gauges against the spec using a wire gauge tool on a sample of internal harnesses.
HRS-3.3.1.7 | A 3.3–5 V bidirectional logic level shifter shall con-dition all 4 TB6600 signal lines (STEP pin 3, DIR pin 4, STEP pin 5, DIR pin 7). | TXS0104E or BSS138-based level shifter module, both TB6600 drivers, Arduino Uno R4 WiFi | Pass – re-moved from scope | May 30, 2026 | No level shifter installed; TB6600 units accept 3.3– 24 V control inputs di-rectly. See Section 2.1.4.
HRS-3.3.2.1 | The system shall accept 100–240 V AC mains power via the 24 V 6 A supply with a 5.5×2.1 mm barrel jack feeding the internal 24 V rail. | 24 V AC/DC sup-ply, barrel jack screw-terminal adapter, 24 V distribution rail | Pass | May 31, 2026 | Confirmed the supply accepted standard wall power and produced a stable 24 V output under load.
HRS-3.3.2.3 | The system shall communi-cate with the Flask server over 2.4 GHz 802.11 b/g/n WiFi in station mode. | Arduino Uno R4 WiFi, WiFi router, Flask backend | Pass | June 1, 2026 | Confirmed the Arduino connected to the network in station mode and ob-tained an IP address.
HRS-3.3.2.4 | The user shall ac-cess the system via a mobile browser at http://{laptop ip}:5000 with no app installation required. | Flask backend, WiFi network, mobile browser | Pass | June 2, 2026 | Loaded the interface from a phone browser with no app installed, as expected.
HRS-3.3.2.5 | The load cell scale platform shall accommodate a bowl with base diameter ≤150 mm and remain level to within 2◦ . | Scale platform, load cell, bowl (measure platform size + level with digital inclinome-ter) | Pass | June 3, 2026 | Measured the platform with a bowl in place and checked level with an in-clinometer; both within spec.
HRS-3.3.2.6 | Each spice module shall present an externally ac-cessible twist-off lid for re-filling without removing the module from the carousel. | 3D-printed module lid and retention mecha-nism | Pass with modifi-cation | June 4, 2026 | Each container has a friction-fit lid, as this was the easiest solution to im-plement given the time constraints.
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

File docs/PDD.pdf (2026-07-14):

ONTARIO TEJ4M COMPUTER ENGINEERING TECHNOLOGY

PRELIMINARY DESIGN DOCUMENT

PROJECT

# Bland2Grand

### Smart Autonomous Carousel Spice Dispensing Appliance

Student Elliott Starosta

Course TEJ4M Computer Engineering Technology

Teacher Mr. Roller

Version 1.0

Date March 2026

Preliminary Design Document Bland2Grand | Version 1.0

### Contents

1 Introduction | 2
2 Product Design | 3
3 Scheduling | 36
A Full System Schematic | 45
B Parts List | 45
C Definitions, Acronyms, and Abbreviations | 47
Mechanical Fabrication Disclaimer | 52
Elliott Starosta • TEJ4M | Page 1 of 52

### 1 Introduction

### 1.1 Project Overview

Bland2Grand is a smart, autonomous countertop spice dispensing appliance designed to remove the guesswork from seasoning food. A user types the name of any dish into a mobile web application, the system retrieves matching spice blend options from a local recipe database, the user selects a blend and a serving count, and the machine autonomously dispenses the precise gram-accurate quantity of each required spice directly into a bowl placed below — with no manual measurement required at any step.

The physical machine is centred on a motorised octagonal carousel. Eight interchangeable trapezoidal spice containers are seated one on each face of the octagon. The carousel is driven by a NEMA 23 stepper motor (M1) mounted centrally below the platform. M1 turns a small pinion gear on its shaft, which meshes externally with a larger ring gear that forms the outer circumference of the carousel platform. Because the gears are in external mesh, the carousel rotates in the opposite direction to the motor shaft. An AS5600 12-bit absolute magnetic encoder (U6) mounted coaxially on the M1 shaft provides closed-loop angular position feedback, allowing the firmware to verify that each of the eight 45° index positions has been correctly reached.

Once the correct container is indexed to the active position, a NEMA 17 stepper motor (M2) fixed to the tower frame directly below the carousel plane, with its shaft pointing upward, drives the dispensing mechanism. M2’s shaft carries a half spur gear — a spur gear with teeth machined on only 180° of its circumference. Each spice container has a full spur gear exposed on its bottom face, connected internally to a horizontal hex shaft that runs through the container body and turns the auger screw inside. As the carousel brings a container to the active position, the container’s full spur gear contacts M2’s half spur gear. When M2 rotates, the toothed half engages the container’s spur gear and transfers rotation through 90° to the hex shaft, turning the auger, which pushes spice through the container’s downward-facing exit into the bowl below. When M2 stops, the toothless half faces the container’s spur gear, providing a positive mechanical cutoff: no torque is transmitted and no passive dripping can occur.

The bowl sits on top of a NOYITO 1 kg load cell (LC1) paired with an HX711 24-bit ADC amplifier module (U3) to provide real-time gram-accurate weight feedback. An Arduino Uno R4 WiFi (U1) coordinates all motion, sensing, and wireless communication with a Flask web server running on a host laptop over the onboard 2.4 GHz 802.11 b/g/n WiFi module.

### 1.2 Document Purpose and Scope

A complete Hardware Requirements Specification (HRS) for this project was written separately. The HRS defines all normative shall requirements and serves as the authoritative design contract between the student designer (Elliott Starosta) and the course teacher (Mr. Roller). This Preliminary Design Document (PDD) describes how those requirements will be met. Specifically, it provides:

- A high-level system block diagram, more detailed than the HRS version and intended as the authoritative reference for evaluation;
- Detailed sub-circuit descriptions supported by engineering theory and calculations;
- Internal and external interface signal tables;
- Pseudocode for both the Arduino C++ firmware and the Python Flask backend;
- The complete project schedule and Gantt chart;
- A full parts list with sourcing links.

The HRS is available alongside this document for reference.

Design Revision Note: Logic Level Shifting

During the initial drafting of the HRS, a logic level shifter between U1 and the TB6600 drivers (U4, U5) was included as a deliberate conservative measure: without yet knowing the exact TB6600 variant that would be sourced, and with the generic TB6600 datasheet citing a 3.5 V high-level input threshold, erring on the side of caution was the correct approach at the requirements stage.
During PDD preparation, the design was revisited with the actual sourced components in hand. The Funsto TB6600 units used for U4 and U5 specify a control signal input range of 3.3–24 V, which directly accommodates the RA4M1 output. Separately, confirming that the Uno R4 WiFi supplies 5 V to the RA4M1 VCC pin places VOH,min at 4.2 V per RA4M1 datasheet Table 2.7 — providing further margin. With specific component specifications now confirmed, the level shifter is no longer required and has been removed from the design. HRS-3.3.1.1, HRS-3.3.1.2, and HRS-3.3.1.7 are superseded by this finding.

### 2 Product Design

### 2.1 System Block Diagram

Figure 1 shows the complete Bland2Grand system partitioned into its major functional sub-circuits. Power flows downward from the 24 V supply (BT1) through the distribution bus to the motor drivers and buck converter. Control signals flow horizontally between the Arduino (U1) and each peripheral. The weight feedback path (LC1 → U3 → U1) closes the gram-accuracy loop, while WiFi bridges U1 to the Flask server and the user’s phone.


Figure 1: Bland2Grand high-level system block diagram, partitioned into its five major sub-circuits. Power distribution is shown in red; motor control in blue; sensor feedback in green; software/communication in orange.

### 2.2 Sub-Circuit Descriptions

Each sub-circuit below corresponds to a labelled functional block in Figure 1. They are presented in the order that power and signals flow through the system:

1. Power System (Sub-Circuit 1) — mains AC enters and establishes the 24 V, 5 V, and 3.3 V rails that every other block depends on.
2. Carousel Drive (Sub-Circuit 2) — uses the 24 V rail to rotate the octagonal platform and position the correct spice container at the dispensing point.
3. Auger Engagement Drive (Sub-Circuit 3) — uses the same 24 V rail to meter spice from the indexed container.
4. Weight Sensing (Sub-Circuit 4) — closes the gram-accuracy loop by feeding real-time mass data back to the Arduino over the 5 V logic rail.
5. Software and Communication (Sub-Circuit 5) — ties all hardware together through firmware running on U1 and the Flask server communicating over WiFi.

### 2.2.1 Sub-Circuit 1: Power System (BT1, U2)

The power system is the foundation of the entire Bland2Grand design. Every other sub-circuit depends on the voltage rails established here, so the power architecture was chosen to be simple, robust, and immediately shut-down-able from a single switch.


Figure 2: Power System block extracted from the high-level block diagram. A single 24 V 6 A supply (BT1) feeds the system through a series-connected SPST rocker switch (SW1), which controls power to the entire 24 V distribution bus. This bus supplies both TB6600 stepper drivers directly. The LM2596S-ADJ buck converter (U2) steps 24 V down to a regulated 5 V logic rail for U1 and U3, while U6 draws 3.3 V from U1’s onboard regulator.

Architecture Overview. The power architecture of Bland2Grand is centred around a single 24 V, 6 A AC/DC switching supply (BT1) and a single-pole single-throw (SPST) rocker switch (SW1) mounted on the tower enclosure. SW1 is placed in series with the positive 24 V line, between BT1’s barrel jack output and the system’s internal 24 V distribution bus.

When SW1 is opened, power is removed from the entire system simultaneously. Both TB6600 stepper motor drivers (U4 and U5) lose their motor supply voltage; U2 loses its input and consequently shuts down the 5 V rail that powers U1 and U3; and U6 loses its 3.3 V supply derived from U1. This design enables an immediate and complete hardwarelevel shutdown, eliminating the need for any software-controlled power-down sequence.

SW1 is rated for 20 A at 24 V DC, providing a fivefold safety margin over the system’s worst-case current draw of 3.7 A. The use of a 24 V supply was chosen deliberately: Both

TB6600 drivers operate within a 9–42 V range, and running at 24 V maximises available torque without requiring an additional high-voltage rail. BT1 features a universal 100–240 V AC input and a centre-positive 5.5×2.1 mm barrel jack output.

Wiring and Voltage Drop Analysis. All 24 V distribution wiring uses 18 AWG stranded wire. The worst-case power run is 300 mm at 2.0 A to driver U4. Using the wire resistance of 0.02093 Ω/m:

Vdrop = I × R = 2.0 × (0.02093 × 0.300) = 12.6 mV

A 12.6 mV drop against a 24 V rail is 0.052% — entirely negligible. Signal wiring uses 22 AWG solid-core jumper wire throughout; currents on signal lines are in the microampere range and produce no measurable voltage drop at these gauges.

Buck Converter (U2): 24 V to 5 V. The Arduino Uno R4 WiFi (U1) and HX711 ADC module (U3) both require a regulated 5 V supply. Deriving this directly from 24 V with a linear regulator would dissipate (24 − 5) × 0.5 = 9.5 W as heat and require a substantial heatsink. Instead, the MECCANIXITY LM2596S-ADJ DC-DC buck converter module (U2) steps 24 V down to 5 V with a typical efficiency of 85–90%, dissipating only about 0.3 W.

The LM2596S is a 150 kHz switching step-down regulator. Internally, an error amplifier maintains a fixed reference voltage of Vref = 1.23V on the ADJ feedback pin. An external resistor divider from the output rail to GND, with the ADJ pin at the midpoint, sets the desired output:

Vout = Vref ×

1 +

R2
R1
= 1.23 ×
1 +

R2
R1

Solving for Vout = 5.0V:
R2
R1

=

Vout

Vref

− 1 =

5.0
1.23

− 1 = 3.065
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

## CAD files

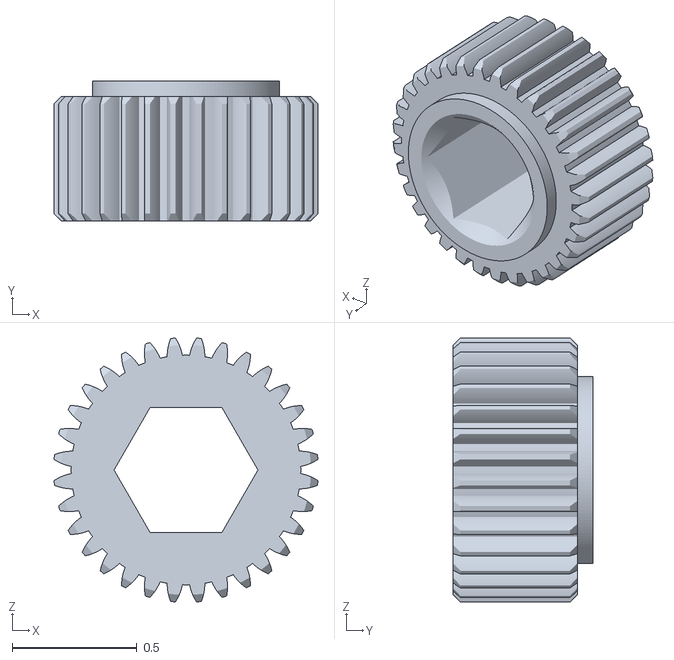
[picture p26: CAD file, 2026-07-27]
CAD/STLS/Auger Mechanism/Auger Power Gear - Auger Full Spur.stl
1.06 x 0.562 x 1.06

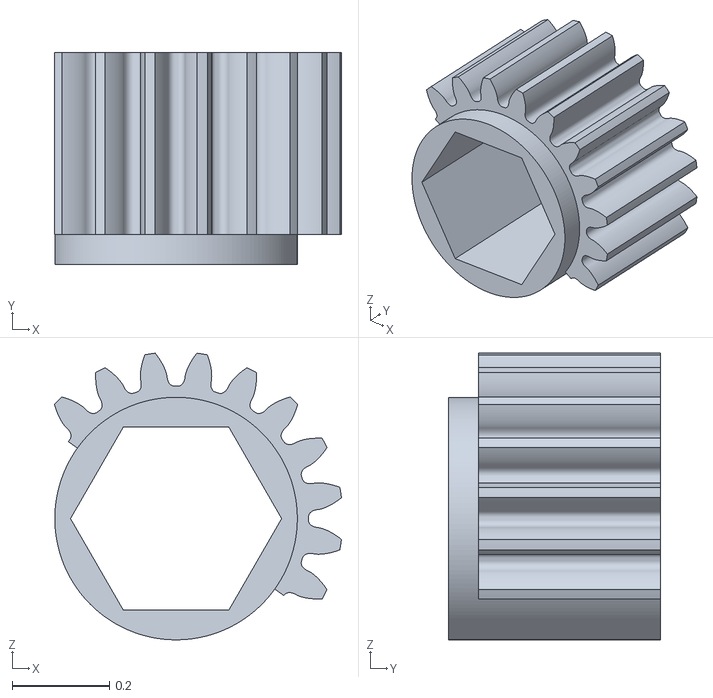
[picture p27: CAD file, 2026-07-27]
CAD/STLS/Auger Motor Accessories/Motor Shaft Auger Power Gear - Auger Half Spur.stl
0.592 x 0.437 x 0.591

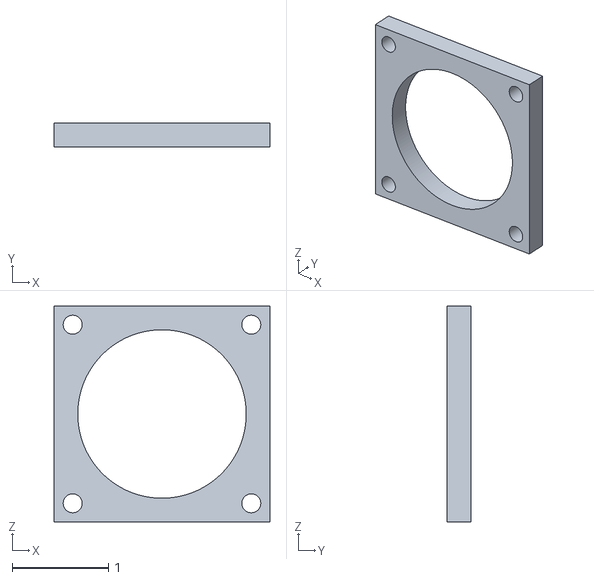
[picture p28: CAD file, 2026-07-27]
CAD/STLS/Carousel Motor Mount/Carousel Motor Mount - Spacer.stl
2.24 x 0.25 x 2.24

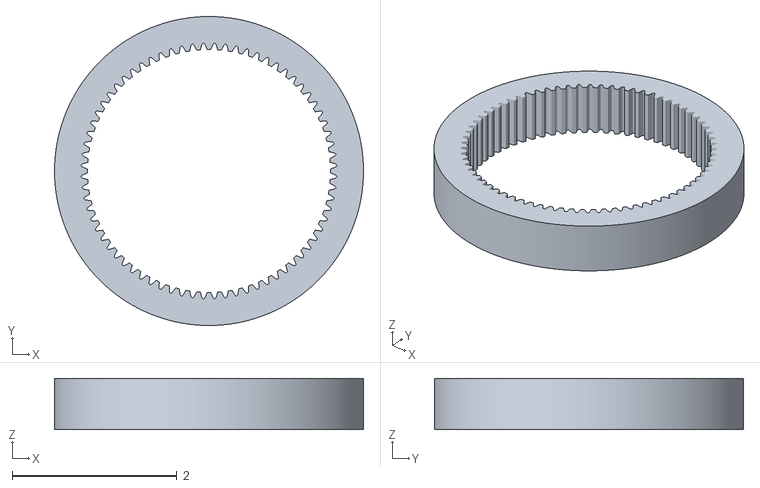
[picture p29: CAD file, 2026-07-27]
CAD/STLS/Exterior Structure/Internal Gear - Internal Gear.stl
3.75 x 3.75 x 0.625

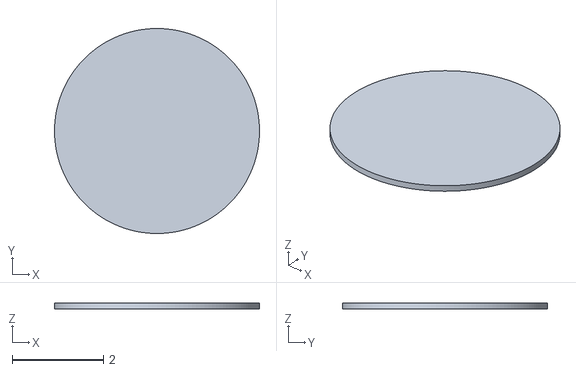
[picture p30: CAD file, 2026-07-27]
CAD/STLS/Plate Holder - Plate Holder.stl
4.50 x 4.50 x 0.125

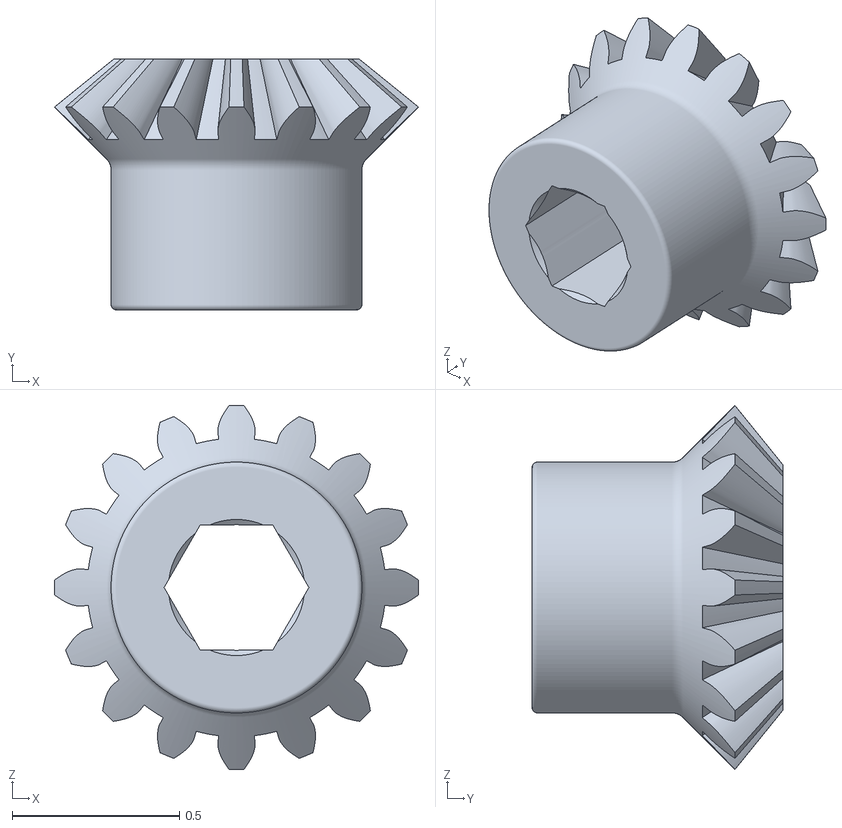
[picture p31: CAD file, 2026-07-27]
CAD/STLS/Auger Mechanism/Bevel Gear - Bevel Gear.stl
1.09 x 0.75 x 1.09

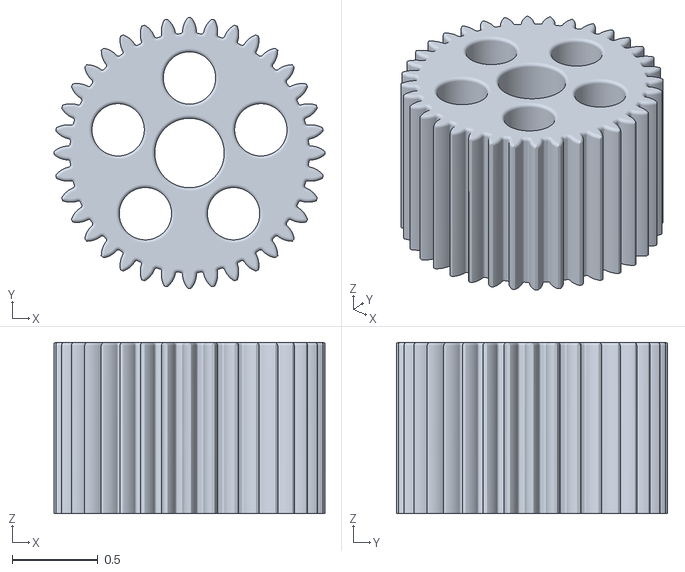
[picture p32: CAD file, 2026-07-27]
CAD/STLS/Carousel Motor Mount/Carousel Drive - Carousel Drive.stl
1.58 x 1.58 x 1

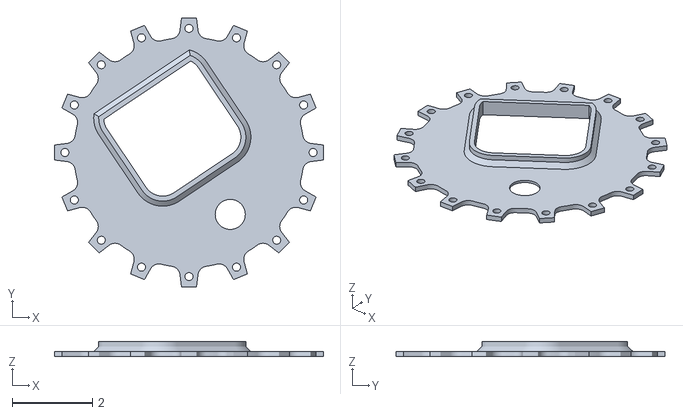
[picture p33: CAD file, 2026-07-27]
CAD/STLS/Exterior Structure/Support Plate - Support Plate.stl
6.72 x 6.72 x 0.375

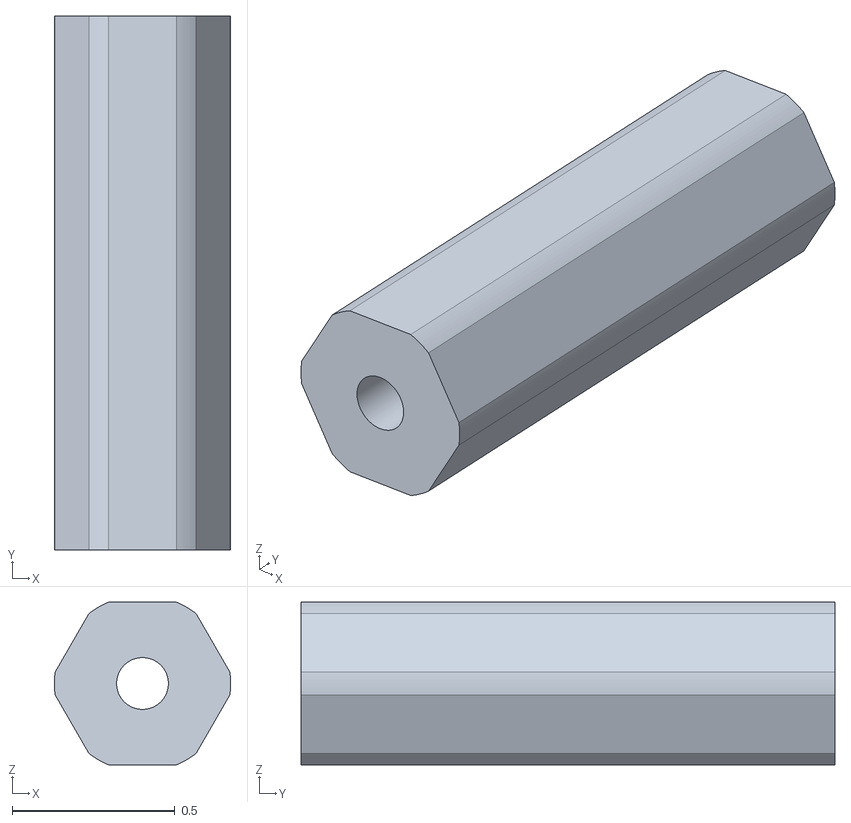
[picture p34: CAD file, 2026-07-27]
CAD/STLS/Auger Mechanism/Auger Power Shaft - Auger Power Shaft.stl
0.541 x 1.64 x 0.5

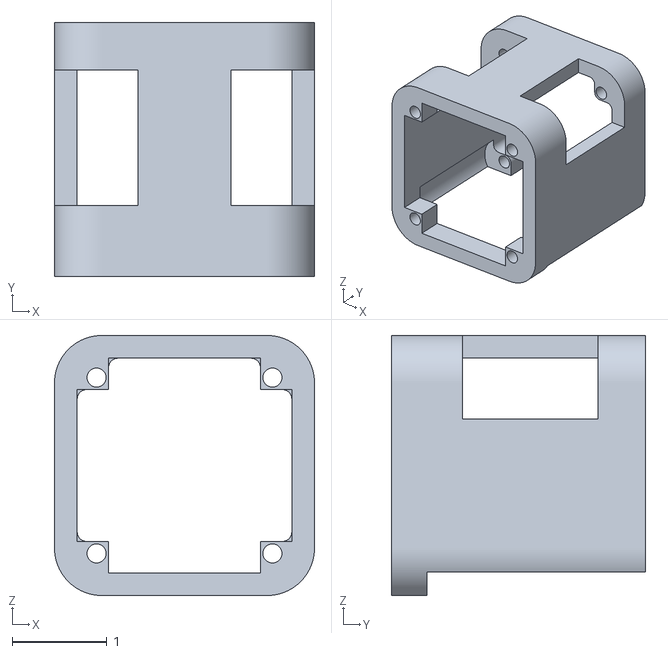
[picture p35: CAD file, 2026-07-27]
CAD/STLS/Carousel Motor Mount/Carousel Motor Mount - Carousel Motor Mount.stl
2.74 x 2.68 x 2.74

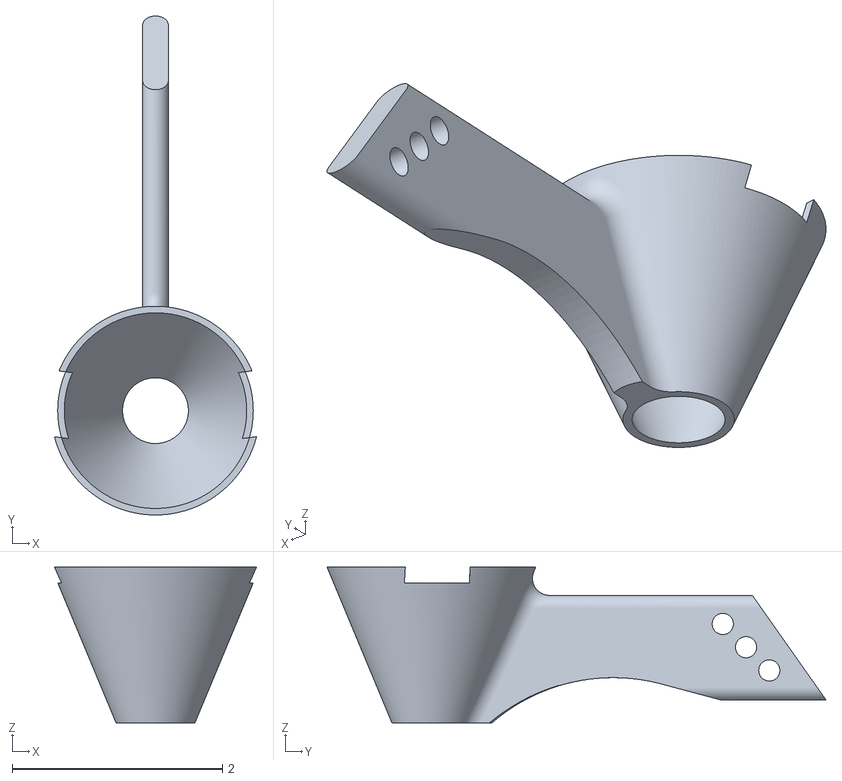
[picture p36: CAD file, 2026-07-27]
CAD/STLS/Exterior Structure/Funnel support - Extension.stl
1.92 x 4.74 x 1.48

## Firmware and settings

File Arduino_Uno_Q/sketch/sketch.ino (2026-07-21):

// USE_LOAD_CELL=1 uses the HX711 scale; 0 estimates weight from motor cycles.
#define USE_LOAD_CELL 1

#include <Arduino.h>
#include <Arduino_RouterBridge.h>
#include <Arduino_LED_Matrix.h>
#include "Constants.h"
#include "BridgeComms.h"
#include "CarouselDriver.h"
#include "AugerDriver.h"

#if USE_LOAD_CELL
#include "Scale.h"
#endif

// LED Matrix frames -- UNO Q's onboard matrix is 8 rows x 13 cols (104 LEDs), one column wider than the R4 WiFi's 8x12. Frames below were padded with an extra trailing column of zeros; redraw them to taste.
ArduinoLEDMatrix matrix;

static uint8_t FRAME_CHECK[8][13] = {
    {0, 0, 0, 0, 0, 0, 0, 0, 0, 1, 0, 0, 0},
    {0, 0, 0, 0, 0, 0, 0, 0, 1, 1, 0, 0, 0},
    {0, 0, 0, 0, 0, 0, 0, 1, 1, 0, 0, 0, 0},
    {0, 1, 0, 0, 0, 0, 1, 1, 0, 0, 0, 0, 0},
    {0, 1, 1, 0, 0, 1, 1, 0, 0, 0, 0, 0, 0},
    {0, 0, 1, 1, 1, 1, 0, 0, 0, 0, 0, 0, 0},
    {0, 0, 0, 1, 1, 0, 0, 0, 0, 0, 0, 0, 0},
    {0, 0, 0, 0, 1, 0, 0, 0, 0, 0, 0, 0, 0},
};

static uint8_t FRAME_X[8][13] = {
    {1, 1, 1, 0, 0, 0, 0, 0, 0, 1, 1, 1, 0},
    {0, 1, 1, 1, 0, 0, 0, 0, 1, 1, 1, 0, 0},
    {0, 0, 1, 1, 1, 0, 0, 1, 1, 1, 0, 0, 0},
    {0, 0, 0, 1, 1, 1, 1, 1, 1, 0, 0, 0, 0},
    {0, 0, 0, 1, 1, 1, 1, 1, 1, 0, 0, 0, 0},
    {0, 0, 1, 1, 1, 0, 0, 1, 1, 1, 0, 0, 0},
    {0, 1, 1, 1, 0, 0, 0, 0, 1, 1, 1, 0, 0},
    {1, 1, 1, 0, 0, 0, 0, 0, 0, 1, 1, 1, 0},
};

// Subsystem instances
BridgeComms wifi; // kept the name "wifi" so Carousel/AugerDriver need zero changes
CarouselDriver carousel(wifi);

#if USE_LOAD_CELL
Scale scale;
AugerDriver auger(wifi, scale);
#else
AugerDriver auger(wifi);
#endif

// Dispense state machine
enum class DispenseState
{
    IDLE,
    WAITING_FOR_BOWL,
    INDEXING,
    DISPENSING,
    PARKING,
    PUSH_COMPLETE,
    DONE
};

DispenseState dispenseState = DispenseState::IDLE;

// Holds the spice Python asked for on the last accepted start_dispense() RPC.
struct ActiveDispense
{
    uint8_t slot = 0;
    char spiceName[24] = {};
    char recipeName[48] = {};
    float targetGrams = 0.0f;
    uint8_t slotIdx = 0;
    uint8_t total = 1;
};

ActiveDispense active;
bool _bowlTared = false;
volatile bool _stopRequested = false;


bool onStartDispense(int slot, float grams, String spiceName,
                     String recipeName, int slotIdx, int total)
{
    if (dispenseState != DispenseState::IDLE)
    {
        Monitor.println(F("[Bridge] start_dispense rejected -- busy"));
        return false;
    }

    active.slot = (uint8_t)(slot & 0xFF);
    active.targetGrams = grams;
    active.slotIdx = (uint8_t)(slotIdx & 0xFF);
    active.total = (uint8_t)(total & 0xFF);

    strncpy(active.recipeName, recipeName.c_str(), sizeof(active.recipeName) - 1);
    strncpy(active.spiceName, spiceName.c_str(), sizeof(active.spiceName) - 1);
    active.recipeName[sizeof(active.recipeName) - 1] = '\0';
    active.spiceName[sizeof(active.spiceName) - 1] = '\0';

    Monitor.print(F("[CMD] slot="));
    Monitor.print(active.slot);
    Monitor.print(F(" grams="));
    Monitor.print(active.targetGrams);
    Monitor.print(F(" spice="));
    Monitor.print(active.spiceName);
    Monitor.print(F(" ("));
    Monitor.print(active.slotIdx + 1);
    Monitor.print(F("/"));
    Monitor.print(active.total);
    Monitor.println(F(")"));

    dispenseState = DispenseState::INDEXING;
    return true;
}

// Called from Python: Bridge.call("stop_dispense")
bool onStopDispense()
{
    Monitor.println(F("[CMD] STOP received -- aborting dispense."));
    _stopRequested = true;
    if (dispenseState != DispenseState::IDLE)
    {
        dispenseState = DispenseState::PUSH_COMPLETE;
    }
    return true;
}

// Called from Python: Bridge.call("get_health")

int onGetHealth()
{
    return (int)carousel.currentSlot();
}

bool onIsBusy()
{
    return dispenseState != DispenseState::IDLE;
}

// State machine tick -- called every loop() 
void tickDispense()
{
    switch (dispenseState)
    {
    case DispenseState::IDLE:
        break;

    case DispenseState::INDEXING:
    {
#if USE_LOAD_CELL
        if (active.slotIdx == 0 && !_bowlTared)
        {
            float bowlWeight = scale.readStable();

            Monitor.print(F("[Bowl] Scale reads: "));
            Monitor.print(bowlWeight, 2);
            Monitor.println(F("g"));

            if (bowlWeight < MIN_BOWL_WEIGHT_G)
            {
                Monitor.println(F("[Bowl] No bowl detected -- waiting..."));
                wifi.pushNoBowl();
                dispenseState = DispenseState::WAITING_FOR_BOWL;
                return;
            }

            Monitor.println(F("[Bowl] Bowl confirmed -- taring..."));
            scale.tare();
            _bowlTared = true;
            Monitor.println(F("[Bowl] Tare complete."));
        }
        else if (active.slotIdx > 0)
        {
            Monitor.println(F("[Bowl] Retaring for next slot..."));
            scale.tare();
            Monitor.println(F("[Bowl] Retare complete."));
        }
#endif

        wifi.pushIndexing(active.slot, active.spiceName,
                          active.slotIdx, active.total);
        auger.enableCoils();
        carousel.goToSlot(active.slot, active.spiceName);
        auger.startDispense(active.slot, active.spiceName,
                            active.targetGrams,
                            active.slotIdx, active.total);
        dispenseState = DispenseState::DISPENSING;
        break;
    }

    case DispenseState::WAITING_FOR_BOWL:
    {
#if USE_LOAD_CELL
        float w = scale.read();

        Monitor.print(F("[Bowl] Waiting... scale="));
        Monitor.print(w, 2);
        Monitor.println(F("g"));

        if (w >= MIN_BOWL_WEIGHT_G)
        {
            Monitor.println(F("[Bowl] Bowl detected! Proceeding..."));
            wifi.pushBowlDetected();
            delay(200);
            dispenseState = DispenseState::INDEXING;
        }
#else
        dispenseState = DispenseState::INDEXING;
#endif
        break;
    }

    case DispenseState::DISPENSING:
    {
        if (_stopRequested)
        {
            _stopRequested = false;
            active.slotIdx = active.total - 1;
            dispenseState = DispenseState::PUSH_COMPLETE;
            break;
        }
        if (auger.tickDispense())
        {
            auger.startPark();
            dispenseState = DispenseState::PARKING;
        }
        break;
    }

    case DispenseState::PARKING:
        if (auger.tickPark())
        {
            auger.finishPark();
            dispenseState = DispenseState::PUSH_COMPLETE;
        }
        break;

    case DispenseState::PUSH_COMPLETE:
        wifi.pushSpiceComplete(active.slot, active.spiceName,
                               active.targetGrams, active.targetGrams,
                               active.slotIdx);

        if (active.slotIdx + 1 >= active.total)
        {
            Monitor.println(F("[CMD] All spices done."));
            wifi.pushSessionComplete(active.recipeName);
            Monitor.println(F("[Carousel] Returning to slot 1..."));
            carousel.goToSlot(1);
            _bowlTared = false;

#if USE_LOAD_CELL
        // After session, tare with bowl+spice still on scale
        delay(500);
        scale.tare();
        Monitor.println(F("[Bowl] Post-session tare. Waiting for bowl removal..."));

        bool bowlRemoved = false;
        while (!bowlRemoved)
        {
            long raw = scale.rawRead(); // raw ADC, uncalibrated
            float w = scale.read();
            Monitor.print(F("[Bowl] raw="));
            Monitor.print(raw);
            Monitor.print(F("  filtered="));
            Monitor.println(w, 3);

            if (raw < 500000L) // large negative ADC count = bowl removed
            {
                bowlRemoved = true;
            }
            delay(200);
        }

        Monitor.println(F("[Bowl] Bowl removed! Settling then retaring..."));
        delay(1000);
        scale.tare();
        Monitor.println(F("[Bowl] Retared to empty scale. Ready for next session."));
#endif
        }
        dispenseState = DispenseState::IDLE;
        break;
    case DispenseState::DONE:
        dispenseState = DispenseState::IDLE;
        break;
    }
}

// setup()
void setup()
{
    Monitor.begin(115200);

    matrix.begin();
    matrix.renderBitmap(FRAME_X, 8, 13); // show X until Bridge is up

#if USE_LOAD_CELL
    Monitor.println(F("[boot] Bland2Grand - closed-loop (load cell)"));
#else
    Monitor.println(F("[boot] Bland2Grand - dead-reckoning mode"));
#endif

    // Subsystems
    carousel.begin();
    auger.begin();

#if USE_LOAD_CELL
    if (!scale.begin())
        Monitor.println(F("[WARN] HX711 not responding -- check wiring."));
    else
        Monitor.println(F("[OK] HX711 scale ready."));
#endif

  
    Bridge.begin();
    Bridge.provide_safe("start_dispense", onStartDispense);
    Bridge.provide_safe("stop_dispense", onStopDispense);
    Bridge.provide_safe("get_health", onGetHealth);
    Bridge.provide_safe("is_busy", onIsBusy);

    matrix.renderBitmap(FRAME_CHECK, 8, 13); // show checkmark once ready

    Monitor.println(F("[boot] ready"));
}

void loop()
{
    // Always tick the state machine (keeps motors smooth)
    tickDispense();
}

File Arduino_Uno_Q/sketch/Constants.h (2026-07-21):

#pragma once

#include <Arduino.h>

// Pin Assignments

// Carousel motor (M1 / NEMA 23 / TB6600) - rotates the spice carousel to bring the selected slot under the auger
static constexpr uint8_t PIN_CAROUSEL_STEP = 5;
static constexpr uint8_t PIN_CAROUSEL_DIR = 7;

// Auger motor (M2 / NEMA 17 / TB6600) - turns the dispensing auger
static constexpr uint8_t PIN_AUGER_STEP = 3;
static constexpr uint8_t PIN_AUGER_DIR = 4;

// HX711 load cell amplifier (weighs the dispensed spice)
static constexpr uint8_t PIN_HX711_DOUT = A1;
static constexpr uint8_t PIN_HX711_SCK = A0;

// Stepper Motor Geometry

// Both motors: 1.8 deg step angle, 1/8 microstepping
static constexpr float STEP_ANGLE_DEG = 1.8f;
static constexpr uint8_t MICROSTEP_DIVISOR = 8;
// Microsteps per full motor shaft revolution (360 / 1.8 * 8 = 1600)
static constexpr uint16_t STEPS_PER_REV = static_cast<uint16_t>(
    360.0f / STEP_ANGLE_DEG * MICROSTEP_DIVISOR); // = 1600

// Carousel Kinematics

// Gear reduction between the carousel motor shaft and the carousel itself
static constexpr float CAROUSEL_GEAR_RATIO = 18.0f;
static constexpr uint8_t CAROUSEL_SLOT_COUNT = 8;
// Angle (at the carousel, not the motor) between adjacent slots
static constexpr float CAROUSEL_SLOT_DEG = 360.0f / CAROUSEL_SLOT_COUNT;

// Motor shaft degrees to move one carousel slot (accounts for gear ratio)
static constexpr float MOTOR_DEG_PER_SLOT = CAROUSEL_SLOT_DEG * CAROUSEL_GEAR_RATIO;

// Microsteps per carousel index move (one slot-to-slot rotation)
static constexpr uint16_t STEPS_PER_SLOT = static_cast<uint16_t>(
    MOTOR_DEG_PER_SLOT / 360.0f * STEPS_PER_REV);

// Homing scan speed while searching for the home sensor/flag (steps/s)
static constexpr float HOMING_SPEED_STEPS_S = 500.0f;

// Normal carousel indexing speed and acceleration (steps/s, steps/s^2)
static constexpr float INDEX_SPEED_STEPS_S = 3000.0f;
static constexpr float INDEX_ACCEL_STEPS_S2 = 500.0f;

// Empirical correction added per slot to counter accumulated mechanical backlash/slip that STEPS_PER_SLOT alone doesn't fully capture
static constexpr uint16_t STEPS_PER_SLOT_CORRECTION = 143;

// Settle delay after index before dispense begins (ms) - lets carousel vibration die down before the auger starts turning
static constexpr uint16_t INDEX_SETTLE_MS = 1000;

// Auger / Half-Spur Gear Geometry

// Microsteps for one full auger revolution (auger drives 1:1 off its motor)
static constexpr uint16_t STEPS_PER_AUGER_CYCLE = STEPS_PER_REV;

// Back-purge: reverse all dispensed steps after each dispense. This sweeps spice back up the helix and re-parks the toothless arc.
static constexpr float BACK_PURGE_SPEED_STEPS_S = 1600.0f;

// Delay after back-purge before disabling coils (ms) -- lets the auger fully stop before power is cut, avoiding a coasting drift
static constexpr uint16_t AUGER_COIL_DISABLE_DELAY_MS = 200;

// Auger Speed Ramp

// Top speed used for bulk (coarse) dispensing (steps/s)
static constexpr float AUGER_FULL_SPEED_STEPS_S = 3200.0f;
// Max speed allowed during fine "nudge" taps near the target weight
static constexpr float AUGER_NUDGE_MAX_SPEED = AUGER_FULL_SPEED_STEPS_S * 0.35f;

// Three-stage closed-loop speed ramp keyed to dispense progress (steps_done / total_steps). Slows the auger down as it approaches target to reduce overshoot.
static constexpr float RAMP_STAGE2_THRESHOLD = 0.80f; // progress fraction to enter stage 2
static constexpr float RAMP_STAGE3_THRESHOLD = 0.95f; // progress fraction to enter stage 3

static constexpr float RAMP_SPEED_STAGE1 = 1.00f; // 0%-80% progress: full speed
static constexpr float RAMP_SPEED_STAGE2 = 0.75f; // 80%-95% progress: 3/4 speed
static constexpr float RAMP_SPEED_STAGE3 = 0.50f; // 95%-100% progress: half speed

// Auger Flow Model - clump / overshoot tuning constants

// Phase 1 (bulk/coast) stops at this fraction of target weight. In-flight spice + any clump release must not push the total past target.
static constexpr float COAST_UNDERSHOOT_RATIO = 0.85f;

// Phase 3 (nudge): how many auger cycles per nudge tap. Smaller = finer control but more settle delays. 1 cycle ~= GRAMS_PER_REV[slot] grams per tap.
static constexpr uint8_t TAP_CYCLES = 1;

// Phase 2/3: how many consecutive stable scale reads before we trust the weight.
// Stability = successive readings within STABLE_BAND_G of each other.
static constexpr uint8_t SETTLE_READS = 3;
static constexpr float STABLE_BAND_G = 0.25f;

// Maximum nudge taps before giving up (prevents infinite loop on stuck auger).
static constexpr uint8_t MAX_TAPS = 30;

// Per-slot coast EMA: how fast the coast estimate adapts (0=never, 1=instant).
static constexpr float COAST_ALPHA = 0.30f;

// Safety: if a single tap delivers more than this many grams, flag it as a clump.
// Useful for Monitor diagnostics; does not abort the dispense.
static constexpr float CLUMP_WARN_G = 0.5f;

// Bridge Push Timing
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

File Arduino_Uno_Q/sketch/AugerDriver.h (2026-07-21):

#pragma once
#include <Arduino.h>
#include <AccelStepper.h>
#include "Constants.h"
#include "BridgeComms.h"
#include "SlotConfig.h"

// Default to dead-reckoning mode unless USE_LOAD_CELL is defined elsewhere (e.g. build flags)
#ifndef USE_LOAD_CELL
#define USE_LOAD_CELL 0
#endif

// Only pull in the Scale (load cell) driver when adaptive closed-loop mode is enabled
#if USE_LOAD_CELL
#include "Scale.h"
#endif

// Drives the auger stepper motor to dispense spice, either by dead-reckoning (fixed steps per gram) or by adaptive closed-loop control using a load cell.
class AugerDriver
{
public:
#if USE_LOAD_CELL
    // Closed-loop constructor: needs both WiFi (for status pushes) and the Scale
    AugerDriver(BridgeComms &wifi, Scale &scale)
        : _stepper(AccelStepper::DRIVER, PIN_AUGER_STEP, PIN_AUGER_DIR),
          _wifi(wifi), _scale(scale)
    {
        // Seed the per-slot learned grams/rev table from the static config defaults
        for (uint8_t s = 1; s <= CAROUSEL_SLOT_COUNT; s++)
            _gramsPerRev[s] = GRAMS_PER_REV[s];
    }
#else
    // Dead-reckoning constructor: only needs WiFi for status pushes
    explicit AugerDriver(BridgeComms &wifi)
        : _stepper(AccelStepper::DRIVER, PIN_AUGER_STEP, PIN_AUGER_DIR),
          _wifi(wifi) {}
#endif

    // One-time setup: configure motion limits and disable the driver coils until needed
    void begin()
    {
        _stepper.setMaxSpeed(AUGER_FULL_SPEED_STEPS_S);
        _stepper.setAcceleration(AUGER_FULL_SPEED_STEPS_S * 4.0f);
        _stepper.setCurrentPosition(0);
        _stepper.disableOutputs();
        Serial.println(F("[Auger] Initialised."));
#if USE_LOAD_CELL
        Serial.println(F("[Auger] Mode: ADAPTIVE CLOSED-LOOP"));
#else
        Serial.println(F("[Auger] Mode: DEAD-RECKONING"));
#endif
    }

    // Energize / de-energize the stepper driver coils
    void enableCoils() { _stepper.enableOutputs(); }
    void disableCoils() { _stepper.disableOutputs(); }

    // Begin dispensing targetGrams of spice from the given slot.
    // slotIdx/total are just used for progress reporting over WiFi.
    void startDispense(uint8_t slot, const char *spiceName,
                       float targetGrams, uint8_t slotIdx, uint8_t total)
    {
        _slot = slot;
        _targetGrams = targetGrams;
        _lastPushMs = millis();

        // Tell the app/dashboard that a dispense has started
        _wifi.pushDispenseStart(slot, spiceName, targetGrams, slotIdx, total);
        _stepper.enableOutputs();

#if USE_LOAD_CELL
        // Adaptive mode: start in BULK phase and reset all tracking state
        _dispensePhase = Phase::BULK;
        _tapCount = 0;
        _lastRevPushed = 0;
        _lastRevWeight = 0.0f;
        _totalSteps = 0;

        // Queue first bulk rev
        _queueBulkRev();

        Serial.print(F("[Auger] Adaptive dispense start, target="));
        Serial.print(targetGrams, 2);
        Serial.println(F("g"));
#else
        // Dead-reckoning mode: compute how many auger cycles are needed based on the fixed grams-per-revolution calibration for this slot
        float gramsPerCycle = GRAMS_PER_REV[slot];
        long cycles = max(1L, static_cast<long>(roundf(targetGrams / gramsPerCycle)));
        _totalSteps = cycles * static_cast<long>(STEPS_PER_AUGER_CYCLE);
        _stepper.setMaxSpeed(AUGER_FULL_SPEED_STEPS_S);
        _stepper.setAcceleration(AUGER_FULL_SPEED_STEPS_S * 4.0f);
        // Move the full computed distance in one go (negative = dispense direction)
        _stepper.move(-_totalSteps);
        Serial.print(F("[Auger] Dead-reckoning: "));
        Serial.print(cycles);
        Serial.print(F(" cycles ("));
        Serial.print(gramsPerCycle, 3);
        Serial.println(F(" g/rev)"));
#endif
    }

    // Call repeatedly from the main loop while dispensing.
    // Returns true once the dispense is complete.
    bool tickDispense()
    {
#if USE_LOAD_CELL
        return _tickLoadCell();
#else
        return _tickDeadReckoning();
#endif
    }

    // Begin moving the auger back to the nearest "parked" position
    // (an exact multiple of one full revolution) so it's aligned for next time
    void startPark()
    {
        long current = _stepper.currentPosition();
        long remainder = current % STEPS_PER_REV;
        if (remainder < 0)
            remainder += STEPS_PER_REV; // normalize negative modulo result
        _parkTarget = (remainder == 0) ? current : current + (STEPS_PER_REV - remainder);

        // Park slowly to avoid overshoot/backlash issues
        _stepper.setMaxSpeed(BACK_PURGE_SPEED_STEPS_S);
        _stepper.setAcceleration(BACK_PURGE_SPEED_STEPS_S * 2.0f);
        _stepper.moveTo(_parkTarget);

        Serial.print(F("[Auger] Parking to "));
        Serial.println(_parkTarget);
    }

    // Call repeatedly while parking. Returns true once the target position is reached.
    bool tickPark()
    {
        _stepper.run();
        return _stepper.distanceToGo() == 0;
    }

    // Called once parking is complete: let the motor settle, then cut power to the coils
    void finishPark()
    {
        delay(AUGER_COIL_DISABLE_DELAY_MS);
        disableCoils();
        _stepper.setCurrentPosition(0);
        Serial.println(F("[Auger] Parked."));
    }

private:
    AccelStepper _stepper;     // underlying stepper motor driver
    BridgeComms &_wifi;        // reference to WiFi comms for status/progress pushes
    long _totalSteps = 0;      // total steps queued/moved for the current dispense
    long _parkTarget = 0;      // absolute step position to park at
    long _lastRevPushed = 0;   // count of bulk revolutions reported so far
    uint8_t _slot = 1;         // slot currently being dispensed from
    float _targetGrams = 0.0f; // target weight for the current dispense
    uint32_t _lastPushMs = 0;  // timestamp of the last WiFi progress push (dead-reckoning)

    // State machine for a single "tap" (small nudge) revolution, broken into
    // sub-segments so speed can be varied within one revolution
    enum class TapPhase
    {
        PRE,     // first quarter rev, full speed
        CONTACT, // middle half rev, slow "contact" speed (where spice actually releases)
        POST,    // last quarter rev, full speed
        DONE
    };
    TapPhase _tapPhase = TapPhase::DONE;
    long _tapRevsRemaining = 0;    // how many more full revs remain in the current tap
    float _tapContactSpeed = 0.0f; // speed used during the CONTACT segment
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

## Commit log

2026-04-18 fix: changes search screen
    [Constants.h, database.py, dispense.py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]
2026-04-25 fix: added carousel pos to not only rely on the encoder
2026-04-26 adjsuted state machine to work w/ flask
    live updating not on the same thread -- I hate arduinos
2026-05-03 Add README for Bland2Grand Arduino firmware
    Added detailed README for Bland2Grand Arduino firmware, including project overview, hardware components, state machine, key algorithms, WiFi provisioning, dependencies, build instructions, calibratio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
2026-05-03 Change project title to 'Bland2Grand — Web Backend'
    Updated project title in README to reflect 'Web Backend'.
2026-06-04 updated universal spice slot code
2026-06-05 only rotates in one direction so there is no backlash
    [CarouselDriver.h]
2026-06-06 Change HX711 pin assignments and remove slot mapping
    Updated HX711 pin mappings and removed slot mapping section.
2026-06-07 updated task.json
    [diff.csv, diff.txt, results.csv]
2026-06-07 Update README to remove test sketches and calibration
    Removed test sketches section and calibration instructions from README.
2026-06-07 Remove slot map section from README
    Removed the slot map section from the README.
2026-06-13 Document spice slots configuration and update process
    Added instructions for updating spice slots and maintaining configuration.
2026-06-21 Rename Bland2Grand HDD — Elliott Starosta.pdf to HDD.pdf
2026-07-05 Added comments to SlotRow.tsx
2026-07-05 docs: add comments to index.ts
    Add explanatory comments for all shared types including Screen, Recipe,
    DispenseSession, SSEEvent, SlotProgress, and unit configuration constants.
2026-07-05 docs: add comments to types.ts
    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
2026-07-05 docs: add comments to shared types in index.ts
    Add explanatory comments for shared types, including Screen, Recipe,
    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
2026-07-05 docs: add comments to App.tsx
    Add explanatory comments for root app shell including screen routing,
    idle timer, dispense SSE integration, and navigation handlers.
2026-07-05 docs: add comments to app.py
    Add explanatory docstring and inline comments for Flask backend including
    all endpoints, SSE streaming, Arduino event hooks, and dispense orchestration.
2026-07-05 docs: add comprehensive comments to dispense.py
    Add docstrings and inline comments for SSE client management, UDP listener,
    Arduino event handlers, mock mode, and main dispense orchestration logic.
2026-07-05 fix: annotate slot status literals to satisfy SlotStatus union type
2026-07-27 feature: added STLs for B2G CAD
    [Auger Power Gear - Auger Full Spur.stl, Auger Power Shaft - Auger Power Shaft.stl, Bevel Gear - Bevel Gear.stl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]
